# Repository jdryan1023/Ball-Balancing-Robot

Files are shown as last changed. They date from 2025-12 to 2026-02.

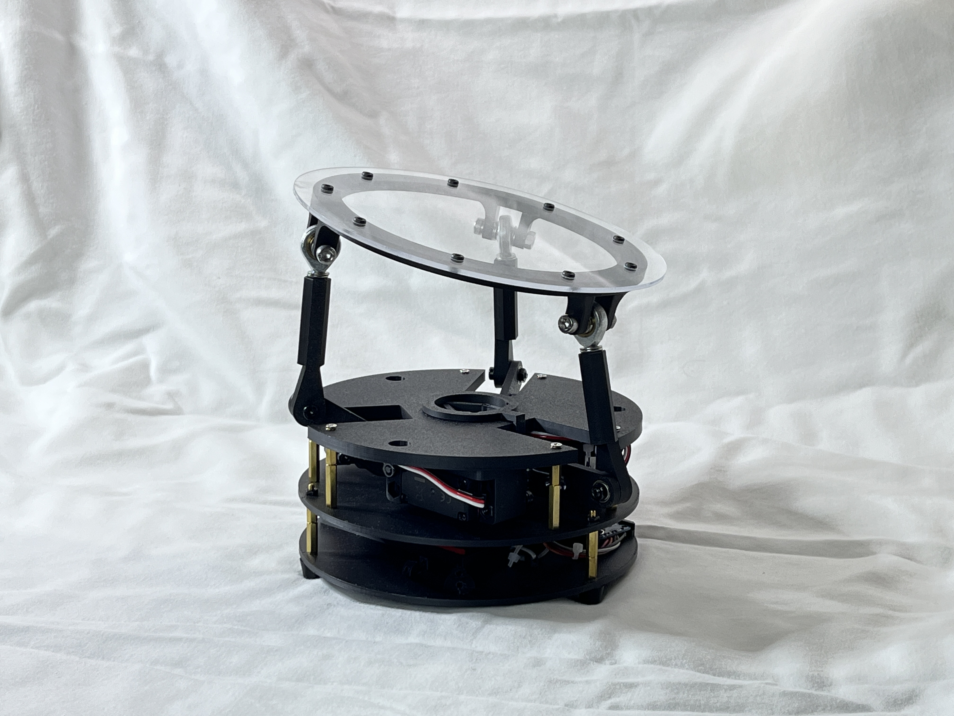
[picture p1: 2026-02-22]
pictures/5.JPG

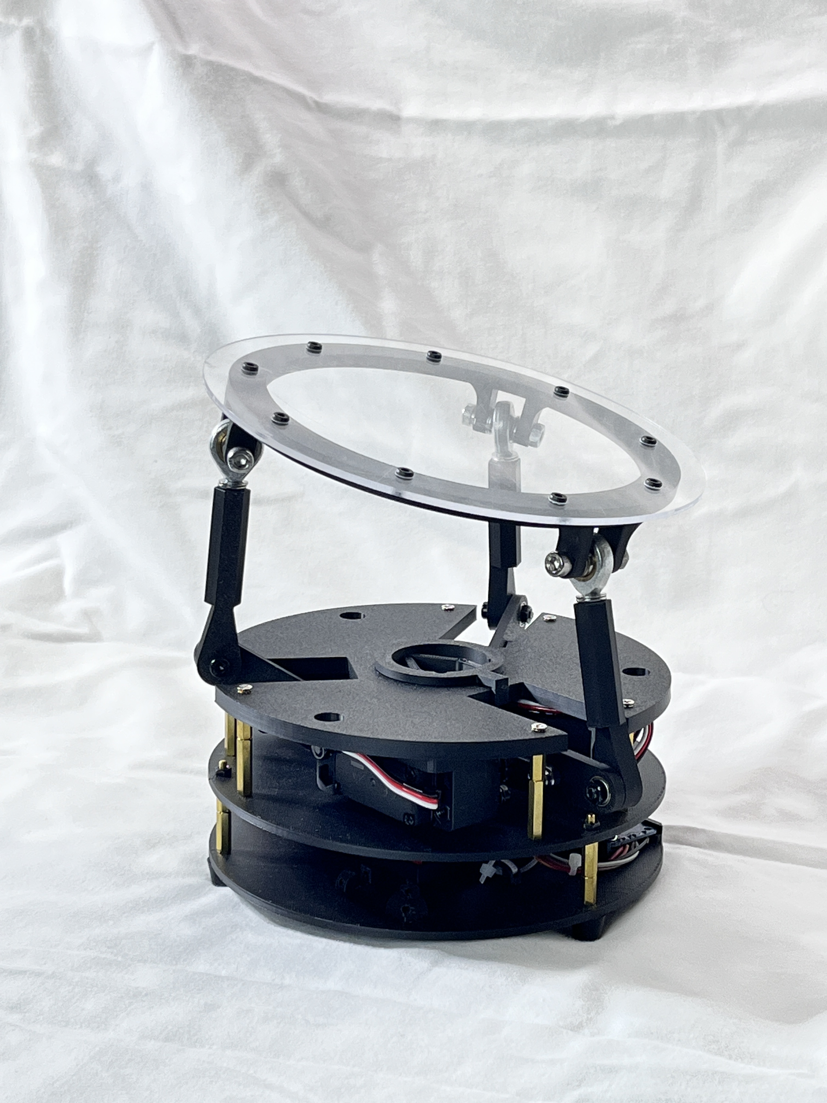
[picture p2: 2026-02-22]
pictures/4.JPG

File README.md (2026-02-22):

# Ball-Balancing-Robot
An educational Ball-Balancing Robot. This project introduces some of the core concepts of robotics: programming, inverse kinematics, computer vision, and PID control.

Discord: https://discord.com/invite/WJuUWsy6DJ

# Video Overview
<div align="center">
  <a href="https://www.youtube.com/watch?v=l92hJUUjWb0&t=6s">
    Watch the video
  </a>
</div>

# Pictures

<div align="center">
  
</div>
<div align="center">
  
</div>

# Build Instruction

The 3D models and print profile for a Bambu A1 printer can be found here: https://makerworld.com/en/models/1197770-ball-balancing-robot#profileId-1210633

# Ballbot – Ball Balancing Robot (Rev 9)

A Raspberry Pi–based ball balancing robot using real-time vision feedback and PID control.

Rev 9 represents a structural milestone:
- Clean `src/` layout package structure
- Separation of HMI and runtime
- Headless-safe runtime operation
- SSH auto-launch capability
- JSON-driven configuration
- Modular subsystem architecture

---

## Getting Started

This section describes the full process from mechanical assembly to first runtime execution.

---

## 1. Mechanical Assembly

### 1.1 Obtain Components

Refer to the Bill of Materials (BOM) for required hardware:

- Raspberry Pi
- Camera module
- PCA9685 I2C servo driver
- Servos
- Power supply
- Ball and platform hardware

---

### 1.2 Print and Assemble Robot Structure

- 3D print structural components.
- Assemble platform and servo linkages.
- Ensure:
  - Platform pivots freely.
  - No binding in linkages.
  - Servo horns are mounted securely.
  - Ball rolls smoothly across platform surface.

Mechanical slop or binding significantly affects control stability.

---

## 2. Raspberry Pi Setup & Electrical Integration

### 2.1 Flash Raspberry Pi OS

- Use Raspberry Pi Imager.
- Install Raspberry Pi OS (Bookworm recommended).
- Enable SSH.
- Configure WiFi if required.
- Set username and password.

Boot the Pi and confirm SSH access.

---

### 2.2 Install Electrical Components

Wire components according to wiring instructions:

- Camera → CSI connector
- PCA9685 → I2C (SDA/SCL)
- Servo power isolated from Pi 5V rail (recommended)
- Common ground between servo supply and Pi

Enable I2C:

```bash
sudo raspi-config
# Interface Options → I2C → Enable
```

Reboot.

Confirm I2C device is detected:

```bash
i2cdetect -y 1
```

You should see the PCA9685 address (typically `0x40`).

---

### 2.3 Install Software

Run installer:

```bash
bash scripts/install.sh
```

This installs:
- Python dependencies
- System libraries
- OpenCV
- libcamera stack

---

## 3. Initial Calibration via HMI

Move Ballbot HMI.desktop to desktop

Launch the HMI:

```bash
hmi
```

The HMI runs over SSH using curses and provides jog controls and calibration tools.

---

### 3.1 Zero Pose Capture (Mechanical Reference)

Before applying offsets, establish a mechanical zero pose.

Procedure:

1. Power the system.
2. Arm the servos.
3. Manually jog the platform until it is visually level.
4. Trigger **Zero Pose Capture** from the HMI.
5. Confirm the pose is recorded.

This step defines the neutral mechanical reference position for the platform. The zero pose is stored and used as the baseline for subsequent offset adjustments.

---

### 3.2 Offset Calibration

After zero pose capture:

1. Fine-adjust X and Y offsets using jog controls.
2. Observe platform level and ball behavior.
3. Save calibration values.
4. Disarm and re-arm to confirm repeatability.

Calibration values are written to:

```
config/calibration.json
```

---

### 3.3 Verification

After calibration:

- Platform should return to level at neutral command.
- No servo drift at idle.
- No bias in ball roll direction.
- Servo sounds should be symmetrical (no constant correction hum).

Accurate zero pose capture is critical for stable PID performance.

---

## 4. Run Runtime (Control Loop)

Start runtime from the HMI or directly:

```bash
bash scripts/run_runtime.sh
```

Runtime performs:
- Frame capture (~60 Hz)
- Vision processing (~50 Hz)
- PID control
- Servo actuation

If running over SSH (headless):
- Video preview is disabled automatically.
- Control loop remains fully functional.

Press `q` to exit runtime safely.

On shutdown:
- Servos disarm.
- Camera terminates cleanly.

---

## First Successful Bring-Up Checklist

Before declaring success:

- Ball remains near center without oscillation.
- No mechanical binding.
- Servos respond smoothly.
- No runaway tilt on startup.
- PID gains stable at low disturbance.

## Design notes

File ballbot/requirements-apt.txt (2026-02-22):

python3
python3-venv
python3-dev
python3-pip

# Camera stack
libcamera-apps
libcamera-dev
python3-picamera2

# I2C tools (PCA9685 debug)
i2c-tools

# Optional (only if you want Qt GUI later)
python3-pyqt5

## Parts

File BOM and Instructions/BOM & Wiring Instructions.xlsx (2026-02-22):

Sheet: Bill of Materials
BOM for Ball Balancing Robot
Item | P/N | QTY | Category | Link
Heat Set Insert Kit (QTY 3 - M4) |  | 1 | Hardware | https://www.amazon.com/dp/B0FH4JQ3VB?ref=ppx_yo2ov_dt_b_fed_asin_title&th=1
HMDI to Micro HDMI Cable |  | 1 | Cabling/Wire | https://www.amazon.com/dp/B08C2PVP7J?ref=ppx_yo2ov_dt_b_fed_asin_title&th=1
20KG RC Servos 4.8V to 6.8V (3Pack) |  | 1 | Electrical HW | https://www.amazon.com/dp/B0CQX9CGMC?ref=ppx_yo2ov_dt_b_fed_asin_title&th=1
Raspberry Pi Camera Module V2 |  | 1 | Electrical HW | https://www.amazon.com/dp/B01ER2SKFS?ref=ppx_yo2ov_dt_b_fed_asin_title
M5 Heim Joints |  | 3 | Hardware | https://www.amazon.com/dp/B0C7N11X1S?ref=ppx_yo2ov_dt_b_fed_asin_title&th=1
Standoff Kit (QTY 9-30mm total height) |  | 1 | Hardware | https://www.amazon.com/dp/B0D48KH1SB?ref=ppx_yo2ov_dt_b_fed_asin_title
Rubber Insulating Feet Kit (3 Required) |  | 1 | Hardware | https://www.amazon.com/dp/B0BFGZW96X?ref=ppx_yo2ov_dt_b_fed_asin_title&th=1
Ball Bearing Kit (3 Required) |  | 1 | Hardware | https://www.amazon.com/dp/B082PSQZMX?ref=ppx_yo2ov_dt_b_fed_asin_title
PCA 9685 |  | 1 | Electrical HW | https://www.amazon.com/dp/B0CRV3MK14?ref=ppx_yo2ov_dt_b_fed_asin_title
Raspberry Pi 4 Model B |  | 1 | Electrical HW | https://www.amazon.com/dp/B09TTNPB4J?ref=ppx_yo2ov_dt_b_fed_asin_title
Dupont Connector Kit |  | 1 | Electrical | https://www.amazon.com/California-JOS-Breadboard-Optional-Multicolored/dp/B0BRTJQGS6?s=industrial
Dupont Jumpers |  | 1 | Electrical | https://www.amazon.com/Mesee-Connector-Assortment-Crimping-Connectors/dp/B09TPHY27V?cv_ct_cx=dupont+connectors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
DC Barrel Jack |  | 1 | Electrical | https://www.amazon.com/dp/B091PS6XQ4?ref=ppx_yo2ov_dt_b_fed_asin_title
DC Power Adapter |  | 1 | Electrical | https://www.amazon.com/dp/B09W96X88K?ref=ppx_yo2ov_dt_b_fed_asin_title
1/8" Clear Circle Acrylic Sheet, 7 Inch Diameter |  | 1 | Robot Component | https://www.amazon.com/dp/B0FPR2WZHT?ref=ppx_yo2ov_dt_b_fed_asin_title
Wire Ferrule Kit |  | 1 | Electrical | https://www.amazon.com/Self-adjustable-AWG-23-7-Electrical-Connectors/dp/B0B23V7ZQJ
Metric socket cap, Class 12.9 alloy steel black oxide finish, 2mm x 0.4mm x 4mm | #13321 (https://boltdepot.com/Product-Details?product=13321) | 8 | Hardware | Boltdepot.com
Metric socket cap, Class 12.9 alloy steel black oxide finish, 3mm x 0.5mm x 8mm | #13635 (https://boltdepot.com/Product-Details?product=13635) | 18 | Hardware | Boltdepot.com
Metric socket cap, Class 12.9 alloy steel black oxide finish, 3mm x 0.5mm x 10mm | #13636 (https://boltdepot.com/Product-Details?product=13636) | 6 | Hardware | Boltdepot.com
Metric socket cap, Class 12.9 alloy steel black oxide finish, 4mm x 0.7mm x 16mm | #6509 (https://boltdepot.com/Product-Details?product=6509) | 3 | Hardware | Boltdepot.com
Metric socket cap, Class 12.9 alloy steel black oxide finish, 4mm x 0.7mm x 30mm | #6512 (https://boltdepot.com/Product-Details?product=6512) | 6 | Hardware | Boltdepot.com
Metric socket cap, Class 12.9 alloy steel black oxide finish, 4mm x 0.7mm x 20mm | #6510 (https://boltdepot.com/Product-Details?product=6510) | 6 | Hardware | Boltdepot.com
Metric socket cap, Class 12.9 alloy steel black oxide finish, 5mm x 0.8mm x 30mm | #6525 (https://boltdepot.com/Product-Details?product=6525) | 3 | Hardware | Boltdepot.com
Metric socket flat head, Class 12.9 alloy steel black oxide finish, 3mm x 0.5mm x 8mm | #13250 (https://boltdepot.com/Product-Details?product=13250) | 9 | Hardware | Boltdepot.com
Metric hex nylon insert lock nuts, Zinc plated class 8.8 steel, 5mm x 0.8mm | #4803 (https://boltdepot.com/Product-Details?product=4803) | 3 | Hardware | Boltdepot.com
Metric hex nylon insert lock nuts, Zinc plated class 8.8 steel, 4mm x 0.7mm | #4802 (https://boltdepot.com/Product-Details?product=4802) | 3 | Hardware | Boltdepot.com
Metric hex nuts, Zinc plated class 8.8 steel, 4mm x 0.7mm | #4784 (https://boltdepot.com/Product-Details?product=4784) | 12 | Hardware | Boltdepot.com
Metric flat washers, Zinc plated steel, 5mm | #4526 (https://boltdepot.com/Product-Details?product=4526) | 27 | Hardware | Boltdepot.com
 | LINKS ^^^^^

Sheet: Wiring Diagram
Wiring Instructions
Raspberry Pi |  |  | PCA9685
6pin (3x2) Dupont |  |  | 6 Pin Dupont (6x1)
Pin1=3.3VDC | Pin3=GPIO2(SDA1) | Pin5=GPIO3(SCL1) | Pin1=empty | Pin2=VCC | Pin3=SDA | Pin4=SCL | Pin5=empty | Pin6=Ground
Pin2 = empty | Pin5=empty | Pin6=Ground
NOTE: | Motor channel mapping can be modified in controller.py -- This scheme matches original code mapping for plug and play.

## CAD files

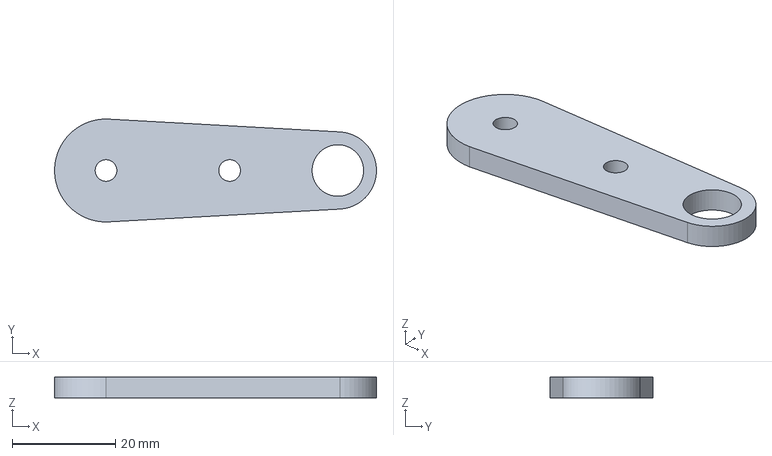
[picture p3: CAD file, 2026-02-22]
model/Link2 v9.step
62.5 x 20.0 x 4.00 mm

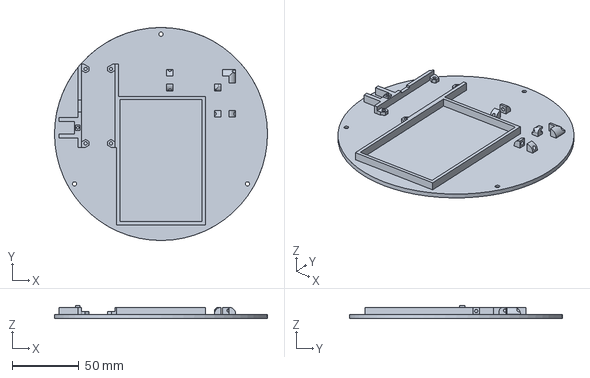
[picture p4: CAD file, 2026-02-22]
model/Bottom v2.step
160.0 x 160.0 x 10.0 mm

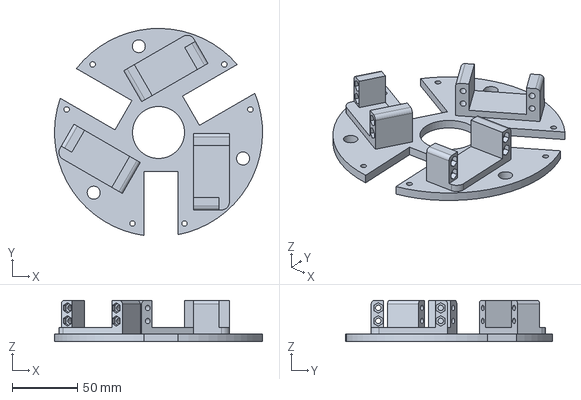
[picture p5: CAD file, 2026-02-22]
model/Base v9.step
159.9 x 159.2 x 31.9 mm

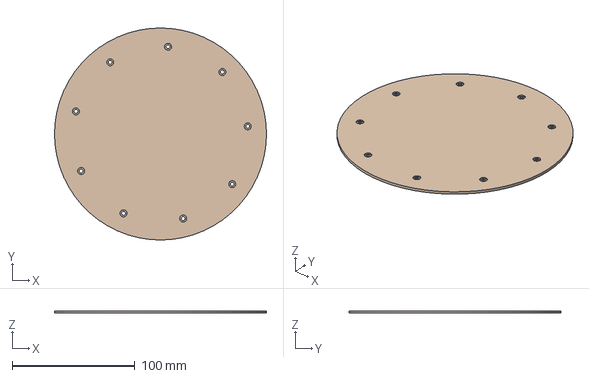
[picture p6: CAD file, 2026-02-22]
model/top_panel v5.step
172.5 x 172.5 x 2.00 mm

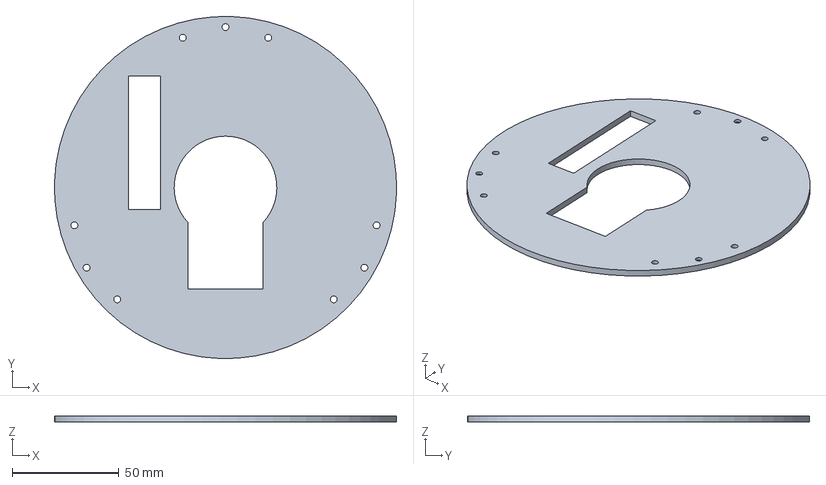
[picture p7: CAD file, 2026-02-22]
model/Middle v2.step
159.9 x 159.9 x 3.00 mm

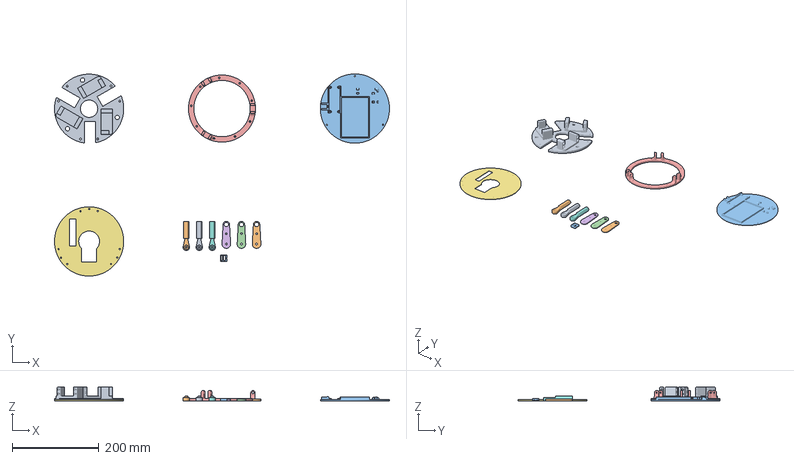
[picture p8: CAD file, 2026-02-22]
model/Print.3mf
774.4 x 467.2 x 31.9 mm
Base v9.step
Link2 v9.step x 3
Bottom v2.step
top_ring v2.step
Middle v2.step
Link1 v7.step x 3
Barrel_Jack_Cover v1.step

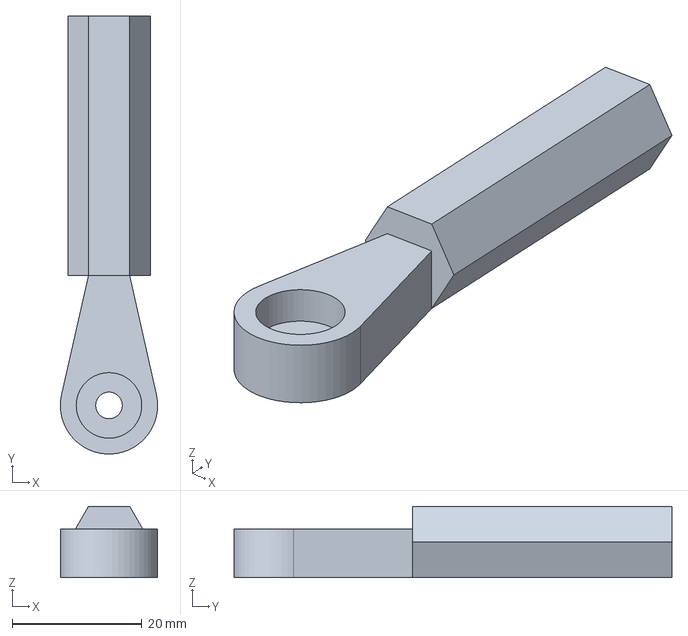
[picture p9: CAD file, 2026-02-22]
model/Link1 v7.step
15.0 x 67.5 x 11.0 mm

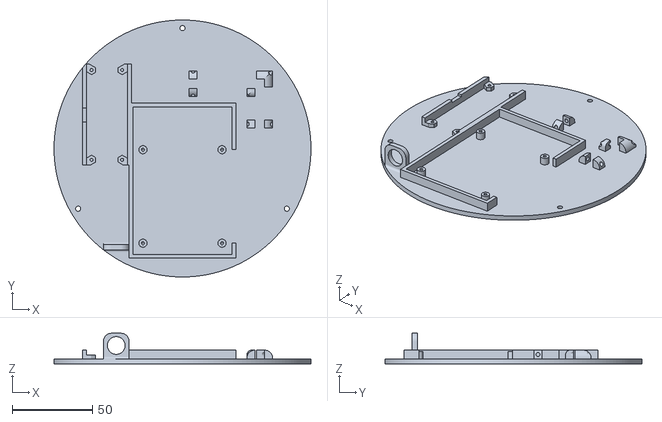
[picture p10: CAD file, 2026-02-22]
model/Bottom Plate Revised Holes R4.STL
160.0 x 160.0 x 19.0

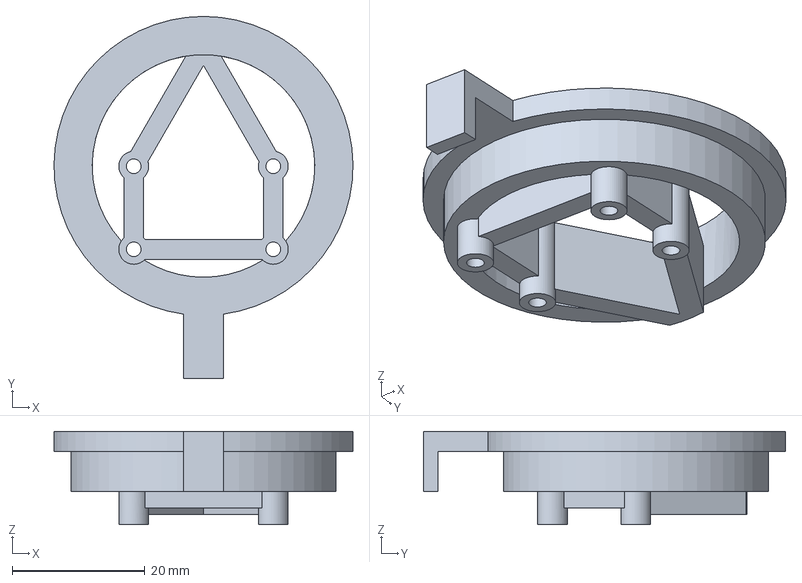
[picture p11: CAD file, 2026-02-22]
model/Camera_Mount v4.step
45.0 x 54.5 x 14.0 mm

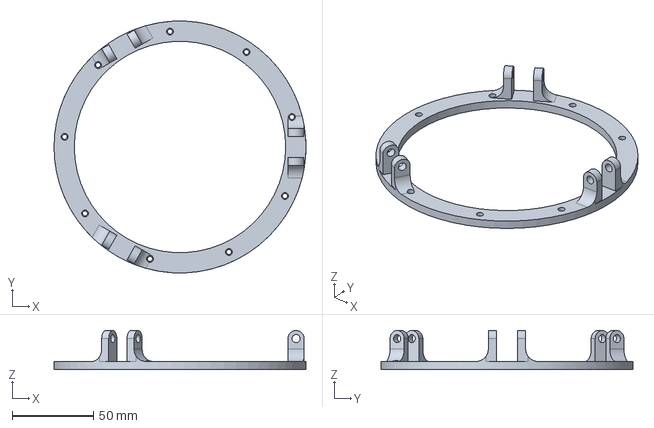
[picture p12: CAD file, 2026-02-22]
model/top_ring v2.step
155.0 x 154.9 x 24.0 mm

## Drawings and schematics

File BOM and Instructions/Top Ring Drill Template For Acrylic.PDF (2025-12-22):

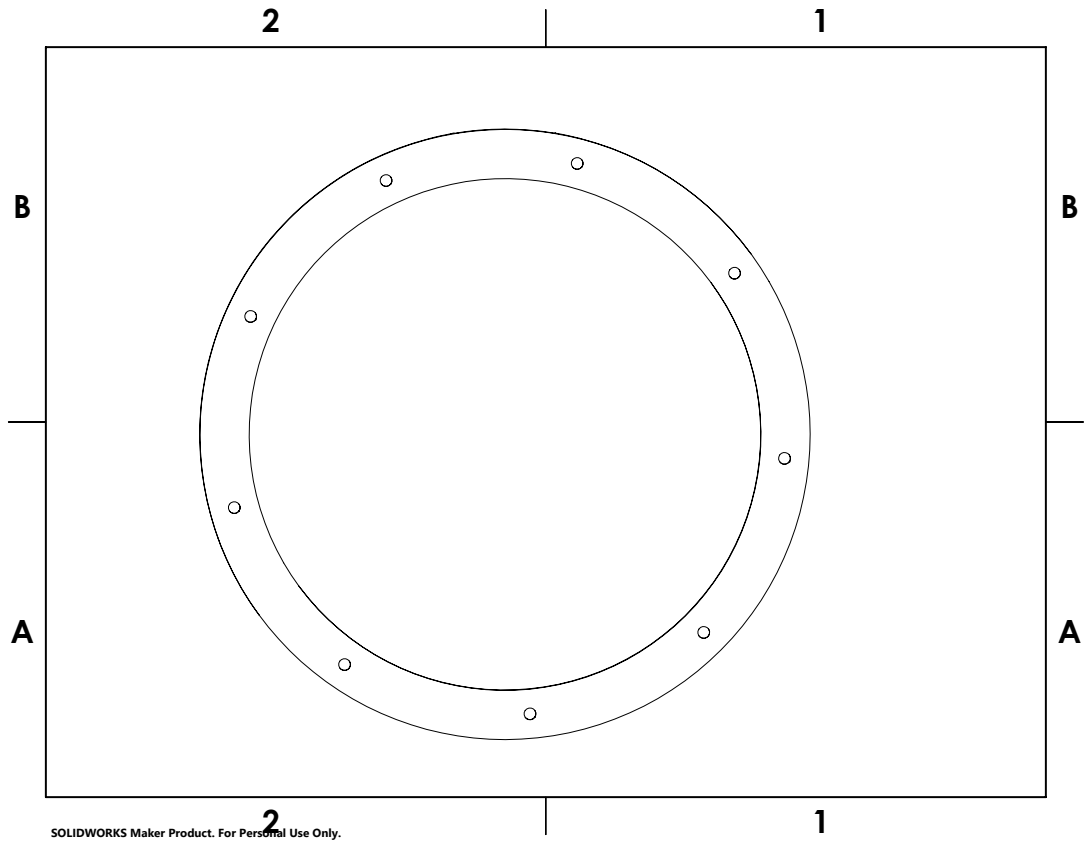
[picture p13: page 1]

SOLIDWORKS Maker Product. For Personal Use Only.

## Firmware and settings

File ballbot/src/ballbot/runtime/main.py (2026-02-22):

# runtime/main.py (rewrite: fixed imports, correct init order, PID JSON only, live debug toggles)

import threading
import time
import cv2
import signal
import numpy as np
import os
import json
from pathlib import Path
from dataclasses import dataclass

from .camera import Camera
from .controller import RobotController
from .robotKinematics import RobotKinematics
from .PID import PIDcontroller
from .debug_overlay import draw_legend

#-----------------------------
# FOR HEADLESS
#-----------------------------
HEADLESS = (os.environ.get("DISPLAY") is None) or (os.environ.get("SSH_CONNECTION") is not None)
# Optional override:
# export BALLBOT_HEADLESS=0 to force GUI
if os.environ.get("BALLBOT_HEADLESS") == "0":
    HEADLESS = False
if os.environ.get("BALLBOT_HEADLESS") == "1":
    HEADLESS = True

# ----------------------------
# Debug flags + monitor
# ----------------------------

@dataclass
class DebugFlags:
    master: bool = False
    cam: bool = False
    cam_mask: bool = False
    ctrl: bool = False
    pid: bool = False
    help: bool = False
    overlay: bool = True


class DebugMonitor:
    def __init__(self):
        self.last_loop_print = 0.0
        self.last_pid_print = 0.0
        self.last_valid = None

    def loop_update(self, *, valid, x, y, elapsed_ms, sleep_ms, period_s=2.0):
        now = time.time()

        # Print immediately on validity changes
        if self.last_valid is None or valid != self.last_valid:
            print(f"[VISION] valid={valid} x={x} y={y}", flush=True)
            self.last_valid = valid
            self.last_loop_print = now
            return

        # Periodic heartbeat
        if now - self.last_loop_print >= period_s:
            print(
                f"[LOOP] valid={valid} x={x} y={y} elapsed={elapsed_ms:.1f}ms sleep={sleep_ms:.1f}ms",
                flush=True,
            )
            self.last_loop_print = now

    def pid_update(self, *, theta, phi, valid, period_s=0.5):
        now = time.time()
        if now - self.last_pid_print >= period_s:
            print(f"[PID] theta={theta:.2f} phi={phi:.1f} valid={valid}", flush=True)
            self.last_pid_print = now


dbg = DebugFlags()
mon = DebugMonitor()


# ----------------------------
# PID config (JSON) loader
# ----------------------------

REPO_ROOT = Path(__file__).resolve().parents[3]
PID_DEFAULTS = {"kp": 0.0063, "ki": 0.00005, "kd": 0.006025, "alpha": 0.65, "beta": 0.3}
PID_PATH = os.getenv("BALLBOT_PID", str(REPO_ROOT / "config" / "pid.json"))


def load_pid(path: str, defaults: dict) -> dict:
    p = Path(path)
    if not p.exists():
        print(f"[PID] file not found: {p} — using defaults", flush=True)
        return defaults.copy()
    try:
        data = json.loads(p.read_text())
        out = defaults.copy()
        for k in defaults.keys():
            if k in data:
                out[k] = float(data[k])
        return out
    except Exception as e:
        print(f"[PID] failed to read {p}: {e} — using defaults", flush=True)
        return defaults.copy()


# ----------------------------
# Initialize subsystems (order matters)
# ----------------------------

cam = Camera()
model = RobotKinematics()
robot = RobotController(model)   # calibration.json auto-loads inside controller
robot.arm()

pid_cfg = load_pid(PID_PATH, PID_DEFAULTS)
kp, ki, kd = pid_cfg["kp"], pid_cfg["ki"], pid_cfg["kd"]
alpha, beta = pid_cfg["alpha"], pid_cfg["beta"]

print(f"[PID] kp={kp} ki={ki} kd={kd} alpha={alpha} beta={beta}", flush=True)

PID = PIDcontroller(kp, ki, kd, alpha, beta, max_theta=model.maxtheta, conversion="tanh")

# Ensure subsystems start quiet (foreground keys toggle these)
cam.debug = False
cam.debug_mask = False
robot.debug = False


# ----------------------------
# Shared state / threads
# ----------------------------

latest_frame = None
frame_lock = threading.Lock()

preview_frame = None
preview_lock = threading.Lock()

running = True
mask_windows_open = False

# State
x, y = 100, 75
x_t, y_t = (100, 75)


def update_robot_pos(x_t, y_t, x, y, valid):
    theta, phi = PID.pid((x_t, y_t), (x, y), valid=valid)
    robot.Goto_N_time_spherical(theta, phi, 8.26)

    if dbg.master and dbg.pid:
        mon.pid_update(theta=theta, phi=phi, valid=valid)


def capture():
    global latest_frame
    hz = 60
    period = 1.0 / hz

    while running:
        t0 = time.perf_counter()
        frame = cam.take_picture()
        with frame_lock:
            latest_frame = frame
        dt = time.perf_counter() - t0
        sleep_time = period - dt
        if sleep_time > 0:
            time.sleep(sleep_time)


def process():
    global x, y, preview_frame
    hz = 50
    period = 1.0 / hz
    preview_div = 5  # ~10 fps preview
    count = 0

    while running:
        loop_start = time.perf_counter()

        with frame_lock:
            frame_copy = None if latest_frame is None else latest_frame.copy()

        if frame_copy is None:
            time.sleep(0.001)
            continue

        # Vision
        x, y, valid = cam.coordinate(frame_copy)

        # Control
        update_robot_pos(x_t, y_t, x, y, valid)

        elapsed = time.perf_counter() - loop_start
        sleep_time = period - elapsed

        # Preview handoff
        count += 1
        if count % preview_div == 0:
            with preview_lock:
                preview_frame = frame_copy.copy()

        # Loop debug
        if dbg.master and dbg.cam:
            mon.loop_update(
                valid=valid,
                x=x, y=y,
                elapsed_ms=elapsed * 1000,
                sleep_ms=max(sleep_time, 0) * 1000,
                period_s=2.0,
            )

        if sleep_time > 0:
            time.sleep(sleep_time)


# ----------------------------
# Shutdown handling
# ----------------------------

def _request_shutdown(signum, frame):
    global running
    print(f"\n[INFO] Signal {signum} received. Shutting down...", flush=True)
    running = False


signal.signal(signal.SIGTERM, _request_shutdown)
signal.signal(signal.SIGINT, _request_shutdown)


# ----------------------------
# Run
# ----------------------------

threading.Thread(target=capture, daemon=True).start()
threading.Thread(target=process, daemon=True).start()
time.sleep(0.5)

print("=" * 60)
print("[INFO] Robot running. Keys: q=quit  t=master  h=help  o=overlay", flush=True)
print("[INFO] When master ON: c=camera  m=mask  r=controller  p=pid", flush=True)
print("=" * 60, flush=True)

try:
    while running:
        # --- Only do OpenCV preview + key polling if GUI is available ---
        if not HEADLESS:
            with preview_lock:
                pf = None if preview_frame is None else preview_frame.copy()

            if pf is not None:
                cam.display_draw(pf, (x, y))
                if dbg.overlay and (dbg.master or dbg.help):
                    draw_legend(pf, dbg)
                cv2.imshow("Tracked Output", pf)

            key = cv2.waitKey(1) & 0xFF

            # mask windows logic only makes sense with GUI
            want_mask = (dbg.master and dbg.cam_mask)
            if want_mask:
                if not mask_windows_open:
                    cv2.namedWindow("mask_dilated", cv2.WINDOW_NORMAL)
                    cv2.namedWindow("grey", cv2.WINDOW_NORMAL)
                    mask_windows_open = True

                m = getattr(cam, "_dbg_mask", None)
                g = getattr(cam, "_dbg_gray", None)
                if m is not None:
                    cv2.imshow("mask_dilated", m)
                if g is not None:
                    cv2.imshow("grey", g)
            else:
                if mask_windows_open:
                    cv2.destroyWindow("mask_dilated")
                    cv2.destroyWindow("grey")
                    mask_windows_open = False

            # handle keys (same as you already have)
            if key == ord("q"):
                break
            if key == ord("h"):
                dbg.help = not dbg.help
                print(f"[DEBUG] help={'ON' if dbg.help else 'OFF'}", flush=True)
            if key == ord("o"):
                dbg.overlay = not dbg.overlay
                print(f"[DEBUG] overlay={'ON' if dbg.overlay else 'OFF'}", flush=True)
            if key == ord("t"):
                dbg.master = not dbg.master
                print(f"[DEBUG] master={'ON' if dbg.master else 'OFF'}", flush=True)
                if not dbg.master:
                    dbg.cam = dbg.cam_mask = dbg.ctrl = dbg.pid = False
                    dbg.help = False
                    cam.debug = cam.debug_mask = False
                    robot.debug = False
            elif dbg.master:
                if key == ord("c"):
                    dbg.cam = not dbg.cam
                    cam.debug = dbg.cam
                elif key == ord("m"):
                    dbg.cam_mask = not dbg.cam_mask
                    cam.debug_mask = dbg.cam_mask
                elif key == ord("r"):
                    dbg.ctrl = not dbg.ctrl
                    robot.debug = dbg.ctrl
                elif key == ord("p"):
                    dbg.pid = not dbg.pid

        else:
            # Headless mode: no imshow / no waitKey.
            # Just keep the robot running and print a heartbeat.
            time.sleep(0.25)

except KeyboardInterrupt:
    print("\n[INFO] Ctrl+C received. Exiting...", flush=True)


finally:
    running = False
    time.sleep(0.05)
    if not HEADLESS:
        try:
            cv2.destroyAllWindows()
        except Exception:
            pass
    robot.disarm()
    cam.terminate()
    print("[INFO] Robot disarmed. Camera closed. Bye.", flush=True)

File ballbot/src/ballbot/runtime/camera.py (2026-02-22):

import time
import cv2
from picamera2 import Picamera2, Preview
import numpy as np
from collections import deque
import threading

class Camera:
    #1640, 1232
    def __init__(self, resolution=(1640, 1232), format="RGB888"):
        self.picam2 = Picamera2()
        config = self.picam2.create_preview_configuration(main={"size": resolution, "format": format}, controls={"FrameDurationLimits": (8333, 8333)})
        self.picam2.configure(config)

        self.lower_black = np.array([0, 0, 0])
        self.upper_black = np.array([179, 255, 50])
        self.gray_threshold = 60

        self.queue = deque(maxlen=16)
        self.queue.append((100, 75))  
        
        self._last_debug_time = 0.0

        self.picam2.start()    

    def take_picture(self):
        image = self.picam2.capture_array()
        scale = 200.0 / image.shape[1]
        frame_resized = cv2.resize(image, (200, int(image.shape[0] * scale)))
        return frame_resized

    def display(self, image, window_name="Camera Output"):
        cv2.imshow(window_name, image)
        cv2.waitKey(1) 

    def display_draw(self, image, center, window_name="Tracked Output"):
        x, y = center
        cv2.line(image, (x - 10, y), (x + 10, y), (0, 0, 255), 2)
        cv2.line(image, (x, y - 10), (x, y + 10), (0, 0, 255), 2)

    def terminate(self):
        self.picam2.stop()
        self.picam2.close()
        cv2.destroyAllWindows()

    def coordinate(self, image):
        frame_blurred = cv2.GaussianBlur(image, (3, 3), 0)

        frame_hsv = cv2.cvtColor(frame_blurred, cv2.COLOR_RGB2HSV)
        frame_gray = cv2.cvtColor(frame_blurred, cv2.COLOR_RGB2GRAY)

        mask_hsv = cv2.inRange(frame_hsv, self.lower_black, self.upper_black)
        mask_gray = cv2.threshold(frame_gray, self.gray_threshold, 255, cv2.THRESH_BINARY_INV)[1]
        mask_combined = cv2.bitwise_or(mask_hsv, mask_gray)

        mask_eroded = cv2.erode(mask_combined, None, iterations=1)
        mask_dilated = cv2.dilate(mask_eroded, None, iterations=1)
        
        if getattr(self, "debug_mask", False):
            # store for main thread to display
            self._dbg_mask = mask_dilated
            self._dbg_gray = frame_gray

        
        valid_detections = []
        contours, _ = cv2.findContours(mask_dilated.copy(), cv2.RETR_EXTERNAL, cv2.CHAIN_APPROX_SIMPLE)

        best_dbg = None

        for contour in contours:
            (cx, cy), radius = cv2.minEnclosingCircle(contour)
            radius = int(radius)
            if radius < 5 or radius > 100:
                continue

            area = cv2.contourArea(contour)
            perimeter = cv2.arcLength(contour, True)
            if perimeter == 0:
                continue

            circularity = (4 * np.pi * area) / (perimeter ** 2)
            if circularity < 0.6:
                continue
            
            if best_dbg is None or area > best_dbg[0]:
                best_dbg = (area, radius, circularity)

            x, y, w, h = cv2.boundingRect(contour)
            valid_detections.append((area, (int(x + w / 2), int(y + h / 2))))

        if valid_detections:
            best_center = max(valid_detections, key=lambda item: item[0])[1]
            self.queue.append(best_center)
            return best_center[0], best_center[1], True
        else:
            now = time.time()
            last = getattr(self, "_last_debug_time", 0.0)
            if self.debug and now - last > 0.5:
                print(f"{now:.3f}  NO DETECTION  contours={len(contours)}")
                self._last_debug_time = now

        # Keep queue stable for drawing, but report invalid to control
        last_center = self.queue[-1]
        self.queue.append(last_center)
        return last_center[0], last_center[1], False



if __name__ == "__main__":
    cam = Camera()
    self.debug = False          # prints
    self.debug_mask = False     # show mask windows

    
    try:
        while True:
            img = cam.take_picture()
            x, y, valid = cam.coordinate(img)

            cam.display_draw(img, (x, y))

            if time.time() - getattr(cam, "_tprint", 0) > 0.5:
                print("center:", (x, y), "valid:", valid)
                cam._tprint = time.time()

            # Exit if 'q' is pressed
            if cv2.waitKey(1) & 0xFF == ord('q'):
                break
    finally:
        cam.terminate()

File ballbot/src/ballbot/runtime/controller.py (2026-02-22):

import os
import json
import time
import math
import logging
from pathlib import Path
from adafruit_servokit import ServoKit


# =============================
# Paths / Config
# =============================

def _repo_root() -> Path:
    # controller.py is in src/ballbot/runtime/
    return Path(__file__).resolve().parents[3]

def _cfg_path(env_key: str, default_rel: str) -> Path:
    return Path(os.getenv(env_key, str(_repo_root() / default_rel)))

CAL_PATH = _cfg_path("BALLBOT_CAL", "config/calibration.json")


# =============================
# Calibration
# =============================

def default_calibration() -> dict:
    """Defaults are SIM-ONLY. HW mode must use a real file."""
    return {
        "s1": {"neutral": 54.0, "gain": 1.0, "offset": 0.0, "zero": 0.0, "min": 10.0, "max": 100.0},
        "s2": {"neutral": 54.0, "gain": 1.0, "offset": 0.0, "zero": 0.0, "min": 10.0, "max": 100.0},
        "s3": {"neutral": 54.0, "gain": 1.0, "offset": 0.0, "zero": 0.0, "min": 10.0, "max": 100.0},
    }

def load_calibration(path: str | Path) -> dict:
    p = Path(path)
    if not p.exists():
        raise RuntimeError(f"Calibration file not found: {p}")
    try:
        return json.loads(p.read_text())
    except Exception as e:
        raise RuntimeError(f"Failed to parse calibration file {p}: {e}")

def _ensure_fields(cal: dict) -> dict:
    """Ensure required keys exist and coerce numeric types."""
    for s in ("s1", "s2", "s3"):
        cal.setdefault(s, {})
        c = cal[s]
        c.setdefault("neutral", 54.0)
        c.setdefault("gain", 1.0)
        c.setdefault("offset", 0.0)
        c.setdefault("zero", 0.0)
        c.setdefault("min", 0.0)
        c.setdefault("max", 180.0)

        # Coerce types
        for k in ("neutral", "gain", "offset", "zero", "min", "max"):
            c[k] = float(c.get(k, 0.0))
    return cal

def apply_cal(angle_cmd: float, cal: dict) -> float:
    """
    angle_cmd: angle from kinematics (MODEL space)
    cal: per-servo calibration dict

    Mapping:
      servo = neutral + gain * (model - zero) + offset
    """
    neutral = float(cal.get("neutral", 54.0))
    gain = float(cal.get("gain", 1.0))
    offset = float(cal.get("offset", 0.0))
    amin = float(cal.get("min", 0.0))
    amax = float(cal.get("max", 180.0))
    zero = float(cal.get("zero", 0.0))

    a = neutral + gain * (angle_cmd - zero) + offset
    if a < amin: a = amin
    if a > amax: a = amax
    return a

def servo_home(cal: dict) -> float:
    """
    A safe-ish servo-space home used for explicit HOME commands (not required on ARM).
    Uses neutral+offset and clamps.
    """
    neutral = float(cal.get("neutral", 54.0))
    offset = float(cal.get("offset", 0.0))
    amin = float(cal.get("min", 0.0))
    amax = float(cal.get("max", 180.0))
    a = neutral + offset
    return max(amin, min(amax, a))


# =============================
# Controller
# =============================

class RobotController:
    def __init__(self, model, calibration_file=None):
        self.robot = model

        # Logging (HMI should capture stdout/stderr; logging still helps)
        self.log = logging.getLogger("ballbot.controller")

        # Hardware enable
        self.hw_enabled = os.getenv("BALLBOT_HW", "1") == "1"
        self.armed = False

        # Setup hardware (if enabled)
        self.kit = None
        self.s1 = self.s2 = self.s3 = None
        if self.hw_enabled:
            self.kit = ServoKit(channels=16)
            self.s1 = self.kit.servo[13]
            self.s2 = self.kit.servo[15]
            self.s3 = self.kit.servo[14]
            for s in (self.s1, self.s2, self.s3):
                s.actuation_range = 270
                s.set_pulse_width_range(500, 2500)

        # Debug / bookkeeping
        self.debug = False
        self._last_cmd = None
        self._last_print_t = 0.0

        # Select calibration source
        cal_mode = os.getenv("BALLBOT_CAL_MODE", "").strip().lower()

        if calibration_file is None:
            calibration_file = "default" if cal_mode in ("default", "none") else CAL_PATH

        if isinstance(calibration_file, str) and calibration_file.strip().lower() in ("default", "none"):
            self.calibration_file = "<defaults>"
            if self.hw_enabled:
                # Hard fail: never allow guessed calibration on real hardware
                raise RuntimeError("Refusing to run with default calibration while BALLBOT_HW=1")
            self.cal = _ensure_fields(default_calibration())
        else:
            self.calibration_file = str(calibration_file)
            self.cal = _ensure_fields(load_calibration(self.calibration_file))

        # Basic print for visibility (HMI may not show; logs should capture)
        print(
            f"RobotController ready. HW={'ON' if self.hw_enabled else 'OFF'} "
            f"Calibration={self.calibration_file}",
            flush=True,
        )
        print(
            f"[CAL] neutrals: "
            f"s1={self.cal['s1'].get('neutral')} "
            f"s2={self.cal['s2'].get('neutral')} "
            f"s3={self.cal['s3'].get('neutral')}",
            flush=True,
        )

    # -----------------------------
    # Servo lifecycle
    # -----------------------------
    def arm(self):
        """
        Arm should NOT move the robot. It simply enables motion commands.
        Make HOME an explicit user action (or ramp-to-home elsewhere).
        """
        if self.armed:
            return
        self.armed = True
        print("Servos armed (no motion)", flush=True)

    def disarm(self, go_home: bool = False):
        if not self.armed:
            return
        print("Disarming servos", flush=True)
        try:
            if self.hw_enabled and go_home:
                # Explicit HOME on disarm if requested (clamped)
                h1 = servo_home(self.cal["s1"])
                h2 = servo_home(self.cal["s2"])
                h3 = servo_home(self.cal["s3"])
                self._force_servo_angles(h1, h2, h3)
                time.sleep(0.25)

            if self.hw_enabled:
                for s in (self.s1, self.s2, self.s3):
                    s.angle = None
        except Exception as e:
            print("Disarm error:", e, flush=True)
        self.armed = False

    # Optional explicit HOME action (safe-ish)
    def home_servos(self, hold_s: float = 0.25):
        if not self.armed or not self.hw_enabled:
            return
        h1 = servo_home(self.cal["s1"])
        h2 = servo_home(self.cal["s2"])
        h3 = servo_home(self.cal["s3"])
        self._force_servo_angles(h1, h2, h3)
        time.sleep(hold_s)

    # -----------------------------
    # Low-level setters
    # -----------------------------
    def _force_angles(self, a1, a2, a3):
        """Input is MODEL space angles."""
        if not self.hw_enabled:
            return
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

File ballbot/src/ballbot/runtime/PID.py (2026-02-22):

import math
import time

class PIDcontroller:
    def __init__(self, kp, ki, kd, alpha, beta, max_theta, conversion="linear"):
        self.kp, self.ki, self.kd = kp, ki, kd
        self.alpha = alpha
        self.beta = beta
        self.max_theta = max_theta

        if conversion == "linear":
            self.magnitude_convert = 1
        elif conversion == "tanh":
            self.magnitude_convert = 0
        else:
            self.magnitude_convert = -1

        self.prev_out_x = 0.0
        self.prev_err_x = 0.0
        self.prev_out_y = 0.0
        self.prev_err_y = 0.0

        self.sum_err_x = 0.0
        self.sum_err_y = 0.0

        self.last_time = None

        # Anti-windup / dropout behavior
        self.I_MAX = 2000.0
        self.dropout_decay = 0.90  # 0.9 -> ramps toward 0 in ~10 cycles

    def pid(self, target, current, valid=True):
        new_time = time.perf_counter()
        dt = (new_time - self.last_time) if self.last_time is not None else (1/50)
        dt = max(0.005, min(0.05, dt))  # clamp dt for stable D/I

        if not valid:
            # Don’t integrate/derivative on junk input. Ramp output toward 0.
            self.prev_out_x *= self.dropout_decay
            self.prev_out_y *= self.dropout_decay
            self.prev_err_x = 0.0
            self.prev_err_y = 0.0
            self.sum_err_x = 0.0
            self.sum_err_y = 0.0
            self.last_time = new_time

            # When theta=0, phi is irrelevant; keep 0 for determinism
            return 0.0, 0.0
           
        # Errors (keeping your sign convention)
        err_x = current[0] - target[0]
        err_y = current[1] - target[1]

        # Integral (once!)
        self.sum_err_x += err_x * dt
        self.sum_err_y += err_y * dt
        self.sum_err_x = max(-self.I_MAX, min(self.I_MAX, self.sum_err_x))
        self.sum_err_y = max(-self.I_MAX, min(self.I_MAX, self.sum_err_y))

        # Derivative
        d_err_x = (err_x - self.prev_err_x) / dt
        d_err_y = (err_y - self.prev_err_y) / dt

        # PID output
        pid_x = self.kp * err_x + self.ki * self.sum_err_x + self.kd * d_err_x
        pid_y = self.kp * err_y + self.ki * self.sum_err_y + self.kd * d_err_y

        # Exponential filter on output
        filtered_x = self.alpha * pid_x + (1 - self.alpha) * self.prev_out_x
        filtered_y = self.alpha * pid_y + (1 - self.alpha) * self.prev_out_y

        # Convert to spherical coordinates
        phi = math.degrees(math.atan2(filtered_y, filtered_x))
        if phi < 0:
            phi += 360.0

        r = math.sqrt(filtered_x**2 + filtered_y**2)
        if self.magnitude_convert == 1:
            theta = min(max(0.0, self.beta * r), self.max_theta)
        else:
            theta = max(0.0, self.max_theta * math.tanh(self.beta * r))

        # State update
        self.prev_err_x = err_x
        self.prev_err_y = err_y
        self.prev_out_x = filtered_x
        self.prev_out_y = filtered_y
        self.last_time = new_time

        return theta, phi

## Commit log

2026-02-22 Add files via upload
    Revision 9 of fork. Major overhaul of code structure, directory dependencies, and ease of use improvements.
    [BOM & Wiring Instructions.xlsx, Base v9.step, Bottom Plate Revised Holes R4.STL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]
2026-02-22 Update README.md
    removed git clone instruction. most will pull repo from browser and it didn't work on powershell.
